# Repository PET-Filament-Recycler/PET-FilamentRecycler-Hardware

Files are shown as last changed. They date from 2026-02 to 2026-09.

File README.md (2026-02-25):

# PET Filament Recycler

A DIY project to recycle PET bottles into 3D printing filament, integrated with an Android app for Bluetooth-based control and monitoring.

---

## Overview

This project builds a machine that cuts PET plastic bottles into strips, then heats and extrudes them into usable 1.75 mm 3D printer filament. An Arduino-based controller manages the heating element and stepper motor via PID control, while an Android app communicates with the machine over Bluetooth to set parameters, start/stop operation, and view command logs.

---

## Features

- **PID temperature control** for the heating block (target: ~200 °C)
- **Stepper motor control** for filament extrusion speed
- **Bluetooth connectivity** (HC-05 / Serial1) for wireless control
- **Android app** with:
  - Bluetooth device discovery and connection
  - Real-time temperature and speed display
  - Start / Stop / Save settings commands
  - Bluetooth command log viewer (SQLite)
- **EEPROM persistence** – temperature and speed settings survive power cycles
- **Custom PCB** design included (GERBER files provided)
- **3D-printable parts** for the mechanical assembly (15 STL files)

---

## Repository Structure

```
PET-Filament-Recycler/
├── 0.1/
│   ├── arduino/
│   │   ├── Firmware_1/          # Original Arduino Nano firmware
│   │   ├── Firmware_1.1/        # Updated Arduino UNO R4 firmware (Bluetooth, EEPROM)
│   │   └── tests/               # Individual component test sketches
│   │       ├── Bluetooth_Test/
│   │       ├── Button_Test/
│   │       ├── LCD_Test/
│   │       ├── PID_Test/
│   │       ├── PWM_Test/
│   │       ├── Stepper_Test/
│   │       └── Thermistor_Test/
│   └── docs/
│       ├── 3D Files STL/        # 3D-printable part files
│       ├── AppLayout/           # UI design mockups (PNG)
│       ├── PCB GERBERs/         # PCB manufacturing files
│       ├── TestResult/          # Component test result photos/videos
│       ├── FlowChart.png        # App ↔ Arduino interaction flow chart
│       └── partList.md          # Bill of materials
└── Android App/                 # Android Studio project (Java)
    └── app/src/main/java/com/petfilament/recycler/
        ├── MainActivity.java
        ├── ControlActivity.java
        ├── BluetoothManager.java
        ├── LogActivity.java
        ├── LogsAdapter.java
        └── DatabaseHelper.java
```

---

## Bill of Materials

| Qty | Component |
|-----|---|
| 1 | Arduino NANO (Firmware 1) / Arduino UNO R4 (Firmware 1.1) |
| 6 | 608ZZ Bearing |
| 1 | NEMA 17 Stepper Motor |
| 1 | I²C LCD Screen (16×2) |
| 1 | TMC2208 Stepper Driver |
| 1 | 3D Printer Aluminum Heating Block |
| 2 | IRF3205 MOSFETs |
| 1 | HC-05 Bluetooth Module |
| 1 | 10 kΩ Potentiometer |
| 1 | Push Button |
| 2 | 3 mm Red LEDs |
| 3 | 10 kΩ Resistors |
| 2 | 10 Ω Resistors |
| 2 | 1.8 kΩ Resistors |
| 1 | 10 µF Capacitor |
| 2 | 100 µF Capacitors |
| — | Female pin headers, screw terminals, M3 screws |

> Full details: [`0.1/docs/partList.md`](0.1/docs/partList.md)

---

## 3D Printed Parts

All STL files are located in [`0.1/docs/3D Files STL/`](0.1/docs/3D%20Files%20STL/).

| File | Description |
|---|---|
| `Board_leg.stl` | PCB mounting leg |
| `Cutter_support.stl` / `Cutter_support_V2.stl` | Bottle-strip cutter support |
| `Filament_aligner.stl` | Guides filament into the heater |
| `Gear_spool_A.stl` / `Gear_spool_B.stl` | Drive gear pair |
| `PET_Spool_A.stl` / `PET_Spool_B.stl` | PET bottle spool halves |
| `PET_Spool_support_A.stl` / `PET_Spool_support_B.stl` | Spool support brackets |
| `Pully.stl` | Motor pulley |
| `Small_gear.stl` | Secondary drive gear |
| `Spool_holder_side_A.stl` / `Spool_holder_side_B.stl` | Spool holder sides |
| `Stepper_support.stl` | NEMA 17 motor mount |

---

## PCB

Gerber files for the custom PCB are in [`0.1/docs/PCB GERBERs/`](0.1/docs/PCB%20GERBERs/). Reference photos of the assembled board are also in [`0.1/docs/`](0.1/docs/).

The circuit is based on the [Electronoobs PET bottle recycler](http://electronoobs.com/eng_arduino_tut174.php) design, with additions for the Bluetooth module.

---

## Arduino Firmware

### Firmware 1 (`0.1/arduino/Firmware_1/`)
- Target board: **Arduino Nano**
- Controls heating element (PID), stepper motor speed (potentiometer), and LCD display.
- Required libraries: `LiquidCrystal_I2C`, `thermistor` ([Electronoobs](https://electronoobs.com/eng_arduino_tut_thermistor.php)), `AccelStepper`

### Firmware 1.1 (`0.1/arduino/Firmware_1.1/`)
- Target board: **Arduino UNO R4 WiFi/Minima**
- Adds Bluetooth serial (`Serial1`) communication and EEPROM settings persistence.
- Replaces the thermistor library with a manual NTC 100 k / β=3950 calculation.
- Required libraries: `hd44780`, `AccelStepper`

#### Supported Bluetooth Commands

| Command | Description |
|---|---|
| `SET_TEMP:<value>` | Set target temperature (0–300 °C) |
| `SET_SPEED:<value>` | Set motor speed (0–1000 steps/s) |
| `START` | Enable stepper motor |
| `STOP` | Disable stepper motor |
| `GET_STATUS` | Returns `TEMP:x,SPEED:x,STATUS:ON/OFF,CONNECTED:yes` |
| `SAVE` | Persist current temperature and speed to EEPROM |

---

## Android App

Located in [`Android App/`](Android%20App/). Open with **Android Studio**.

### Screens

| Activity | Description |
|---|---|
| `MainActivity` | Home screen; navigate to Control screen |
| `ControlActivity` | Bluetooth discovery, connection, machine control, live status |
| `LogActivity` | View history of all sent/received Bluetooth commands |

### Permissions Required

- `BLUETOOTH_SCAN` / `BLUETOOTH_CONNECT` (Android 12+)
- `ACCESS_FINE_LOCATION` (required for Bluetooth scanning on all versions)

### Build

1. Open the `Android App/` folder in Android Studio.
2. Sync Gradle and build the project.
3. Install on a device running Android 8.0 (API 26) or later.

---

## Setup & Usage

1. **Print** all 3D parts and assemble the mechanical frame.
2. **Solder** the PCB using the GERBER files and the parts list above.
3. **Flash** the Arduino firmware using the Arduino IDE.
4. **Pair** your Android phone with the HC-05 Bluetooth module (default PIN: `1234`).
5. **Install** the Android app on your phone.
6. Open the app, tap **Navigate → Control**, then select the HC-05 device and tap **Connect**.
7. Set the desired temperature and speed, tap **Save**, then tap **Start** to begin extruding.
8. Monitor live temperature and speed on the Control screen, or tap **View Logs** to review command history.

---

## References

- Electronoobs PET Recycler Tutorial: <http://electronoobs.com/eng_arduino_tut174.php>
- HC-05 Bluetooth Module Guide: <https://www.electronicshub.org/arduino-hc-05-bluetooth-module-tutorial/>

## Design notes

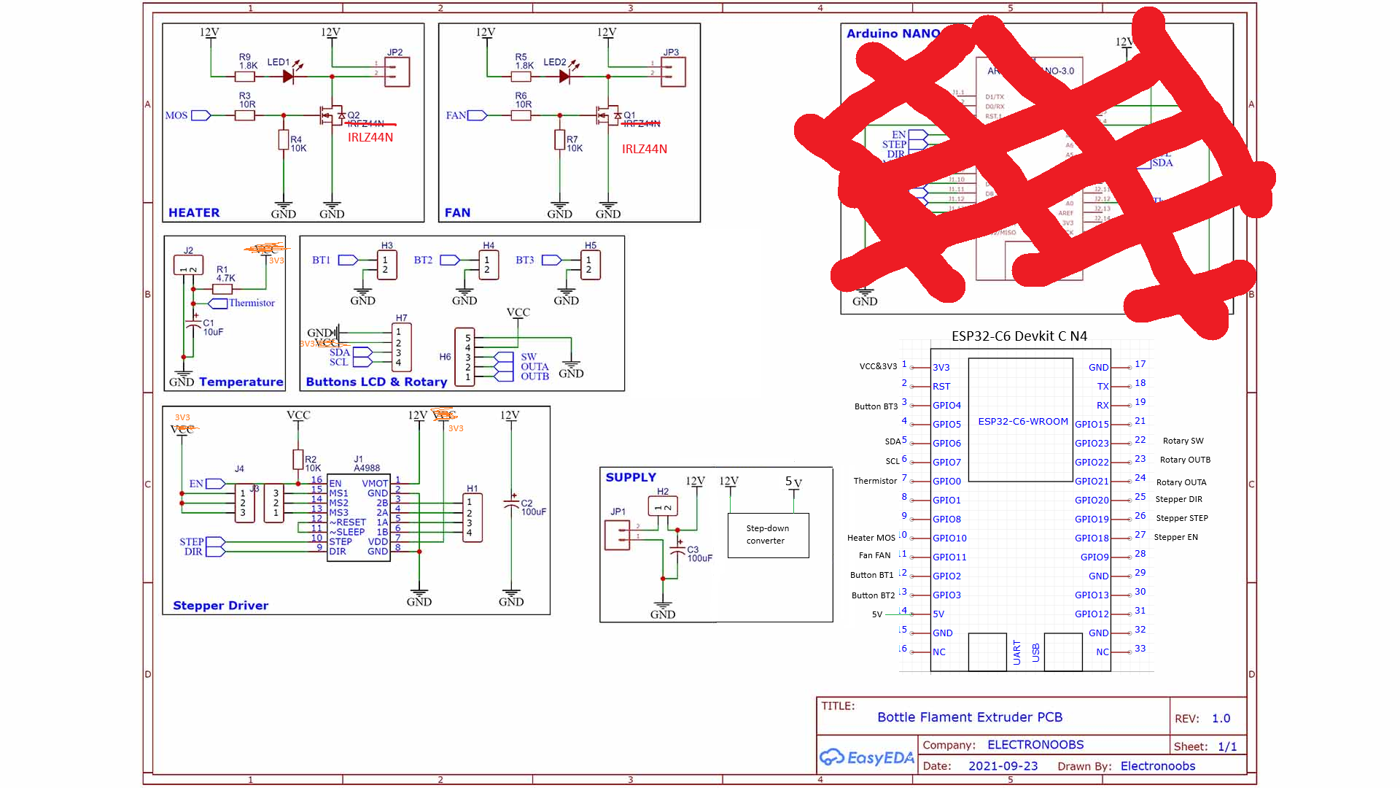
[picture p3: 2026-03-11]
0.2/docs/bottle Flament Extruder PCB ESP32 v1.png

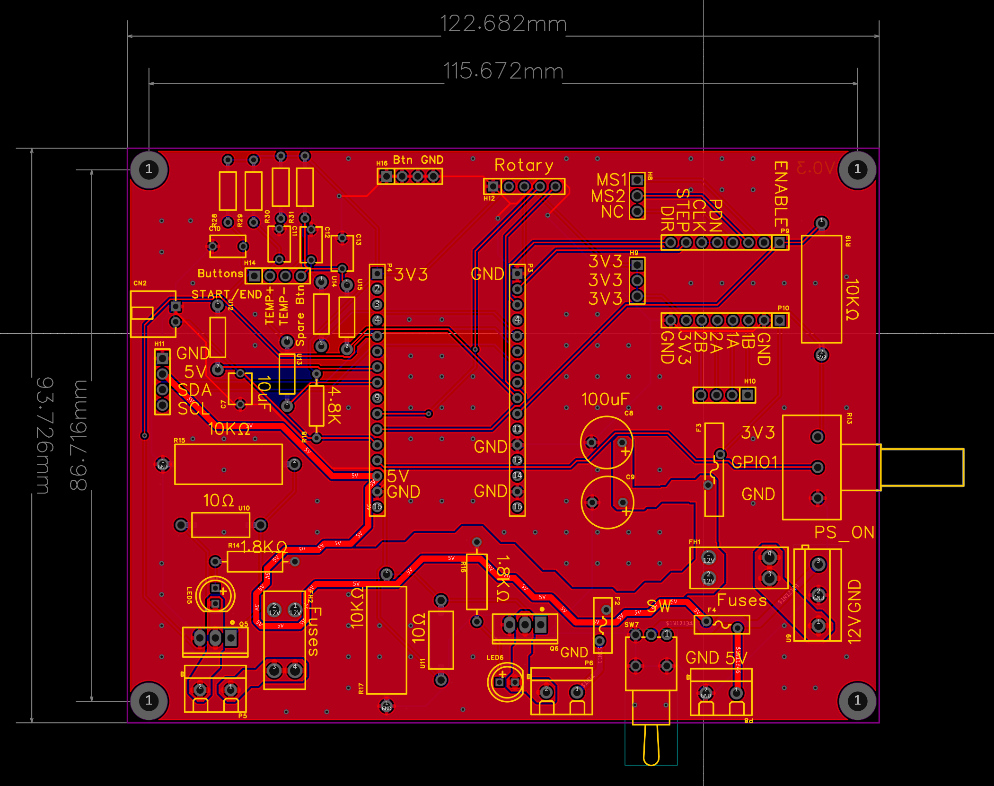
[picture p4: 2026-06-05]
0.2/docs/bottle Flament Extruder PCB ESP32 v3.png

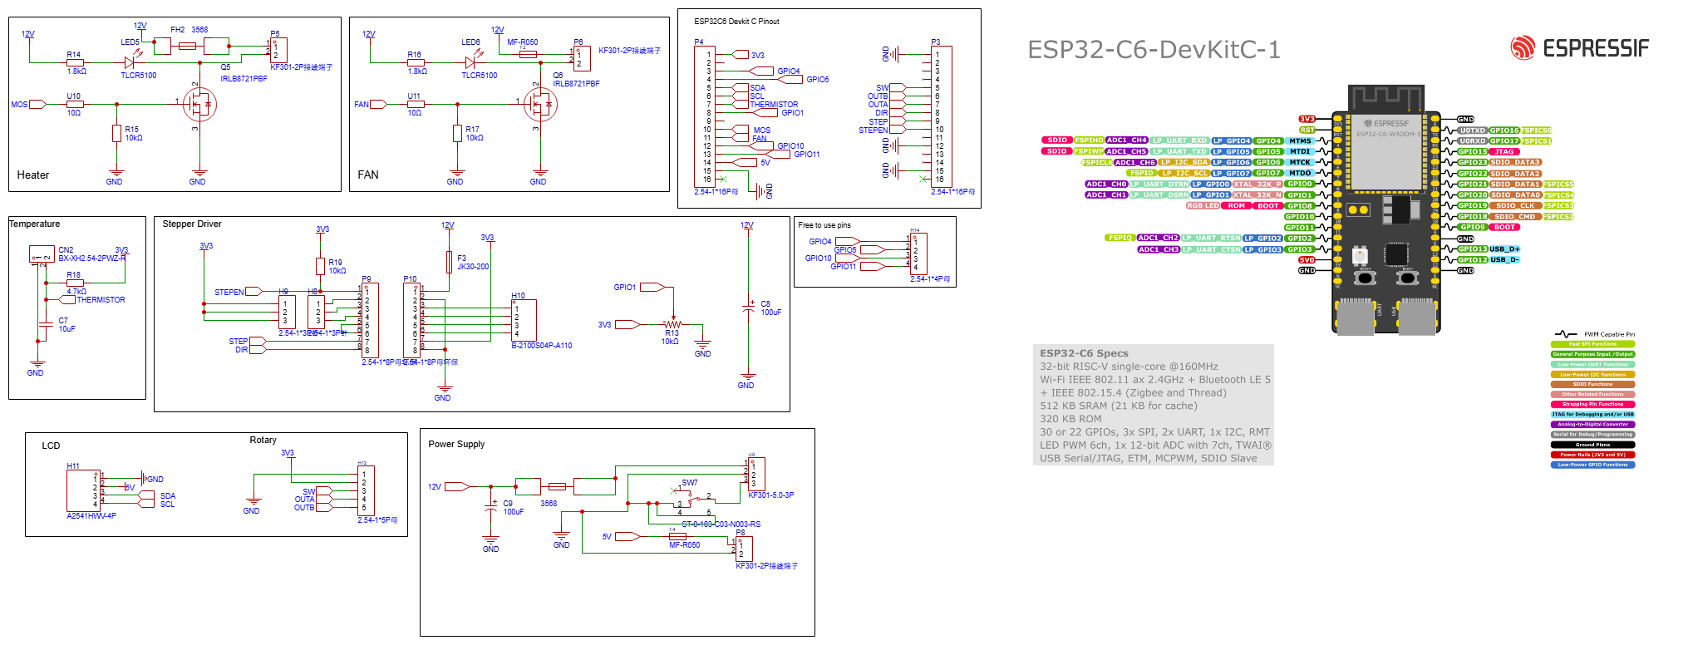
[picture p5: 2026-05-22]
0.2/docs/bottle Flament Extruder SCH ESP32 v2.png

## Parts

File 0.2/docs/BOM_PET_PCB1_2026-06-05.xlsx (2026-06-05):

No. | Quantity | Comment | Designator | Footprint | Value | Manufacturer Part | Manufacturer | Supplier Part | Supplier | Primary Category | Secondary Category | Pin Count | LCSC Stock | LCSC Price | JLCPCB Stock | JLCPCB Price | Layer | Mounting Style | Add into BOM | Convert to PCB | 3D Model Title | Device | Name | Unique ID | Fuse Type
1 | 1 | 10uF | C7 | CAP-TH_L5.1-W3.8-P5.08-D0.5 | 10uF | C322C106K3R5TA | KEMET(基美) | C1623600 | LCSC | Capacitors | Multilayer Ceramic Capacitors MLCC - Leaded | 2 |  |  | 0 | 0.0455 | T | DIP | yes |  | CAP-TH_L5.1-W3.8-P5.08-D0.5 | C322C106K3R5TA | 10uF | gge53
2 | 2 | 100uF | C8,C9 | CAP-TH_BD8.2-P5.00-D0.6-FD_MAL211650101E3 | 100uF | MAL211650101E3 | VISHAY(威世) | C1600087 | LCSC | Capacitors | Aluminum Electrolytic Capacitors - Leaded | 2 |  |  | 341 | 0.1743 | T | DIP | yes |  | CAP-TH_BD8.2-P5.00-D0.6-FD_MAL211650101E3 | MAL211650101E3 | 100uF | gge56,gge57
3 | 4 | 100nF | C10,C11,C12,C13 | CAP-TH_L5.8-W3.6-P5.0-D0.6 | 100nF | 178MU0002 | KNSCHA(科尼盛) | C5632426 | LCSC | Capacitors | Multilayer Ceramic Capacitors MLCC - Leaded | 2 |  |  | 144738 | 0.0021 | T | DIP | yes |  | CAP-TH_L5.8-W3.6-P5.0-D0.6 | 178MU0002 | 100nF | gge64,gge65,gge66,gge67
4 | 1 | BX-XH2.54-2PWZ-R | CN2 | CONN-TH_2P-P2.50_BX-XH2.54-2PWZ |  | BX-XH2.54-2PWZ-R | Bossie(博锡) | C22388493 | LCSC | Connectors | Wire To Board Connector | 2 |  |  | 9214 | 0.0028 | T | DIP | yes |  | CONN-TH_2P-P2.50_BX-XH2.54-2PWZ | BX-XH2.54-2PWZ-R | BX-XH2.54-2PWZ-R | gge15
5 | 2 | MF-R050 | F2,F4 | FUSE-TH_L9.0-W3.0-P5.10-D0.6-S1.10 |  | MF-R050 | BOURNS | C208476 | LCSC | Circuit Protection | Resettable Fuses | 2 |  |  | 840 | 0.0203 | T | DIP | yes |  | FUSE-TH_L8.9-W3.0-H13.5-P5.1-D0.5-S1.1 | MF-R050 | MF-R050 | gge50,gge58
6 | 1 | JK30-200 | F3 | FUSE-TH_L15.2-W3.0-P5.10-D0.50-S2.00 |  | JK30-200 | JK(金科) | C369104 | LCSC | Circuit Protection | Resettable Fuses | 2 |  |  | 23203 | 0.0088 | T | DIP | yes |  | FUSE-TH_L15.2-W3.0-H15.2-P5.10-D0.8-S2.00 | JK30-200_C369104 | JK30-200 | gge55
7 | 2 | 3568 | FH1,FH2 | FUSE-SMD_4P-L16.0-W6.7-P3.40 |  | 3568 | Keystone | C5249699 | LCSC | Circuit Protection | Fuseholders | 4 |  |  | 3478 | 0.2129 | T | DIP | yes |  | FUSE-TH_4P-L16.0-W6.7-P3.40 | 3568 | 3568 | gge30,gge31 | Blade
8 | 2 | 2.54-1*3P针 | H8,H9 | HDR-TH_3P-P2.54-V-M-1 |  | 2.54-1*3P针 | BOOMELE(博穆精密) | C49257 | LCSC | Connectors | Pin Headers | 3 |  |  | 468060 | 0.0036 | T | DIP | yes |  | HDR-M-2.54_1x3 | 2.54-1*3P针 | 2.54-1*3P针 | gge20,gge21
9 | 1 | B-2100S04P-A110 | H10 | HDR-TH_4P-P2.54-V-M |  | B-2100S04P-A110 | Ckmtw(灿科盟) | C124378 | LCSC | Connectors | Pin Headers | 4 |  |  | 79752 | 0.0082 | T | DIP | yes |  | HDR-TH_4P-P2.54-M-LI-1X4P | B-2100S04P-A110 | B-2100S04P-A110 | gge22
10 | 1 | A2541HWV-4P | H11 | HDR-TH_4P-P2.54-V_A2541HWV-4P |  | A2541HWV-4P | CJT(长江连接器) | C225501 | LCSC | Connectors | Female Headers | 4 |  |  | 0 | 0.0152 | T | DIP | yes |  | HDR-F-2.54_1x4 | A2541HWV-4P | A2541HWV-4P | gge25
11 | 1 | 2.54-1*5P母 | H12 | HDR-TH_5P-P2.54-V-F |  | 2.54-1*5P母 | BOOMELE(博穆精密) | C50950 | LCSC | Connectors | Female Headers | 5 |  |  | 156236 | 0.0119 | T | DIP | yes |  | HDR-TH_5P-P2.54-V-F | 2.54-1*5P母 | 2.54-1*5P母 | gge26
12 | 2 | 2.54-1*4P母 | H14,H16 | HDR-TH_4P-P2.54-V-F |  | 2.54-1*4P母 | BOOMELE(博穆精密) | C2718488 | LCSC | Connectors | Female Headers | 4 |  |  | 185971 | 0.0115 | T | DIP | yes |  | HDR-TH_4P-P2.54-V-F | 2.54-1*4P母 | 2.54-1*4P母 | gge36,gge36_2
13 | 2 | TLCR5100 | LED5,LED6 | ED-TH_BD5.8-P2.54-R-FD |  | TLCR5100 | VISHAY(威世) | C7069388 | LCSC | Optoelectronics | LED Indication - Discrete | 2 |  |  | 7277 | 0.0671 | T | DIP | yes |  | ED-TH_BD5.8-P2.54-R-FD | TLCR5100 | TLCR5100 | gge45,gge45_1
14 | 2 | 2.54-1*16P母 | P3,P4 | HDR-TH_16P-P2.54-V-F-1 |  | 2.54-1*16P母 | BOOMELE(博穆精密) | C66987 | LCSC | Connectors | Female Headers | 16 |  |  | 2944 | 0.0157 | T | DIP | yes |  | HDR2.54-F-LI-1X16P | 2.54-1*16P母 | 2.54-1*16P母 | gge1,gge2
15 | 3 | KF301-2P接线端子 | P5,P6,P8 | CONN-TH_XY301V-A-5.0-2P |  | KF301-2P接线端子 |  | C9900016950 | LCSC |  |  | 2 |  |  | 0 | 0.0059 | T | DIP | yes |  | CONN-TH_XY301V-A-5.0-2P | KF301-2P接线端子 | KF301-2P接线端子 | gge7,gge10,gge38
16 | 2 | 2.54-1*8P母环保 | P9,P10 | HDR-TH_8P-P2.54-V-F |  | 2.54-1*8P母环保 | BOOMELE(博穆精密) | C27438 | LCSC | Connectors | Female Headers | 8 |  |  | 163707 | 0.0158 | T | DIP | yes |  | HDR-TH_8P-P2.54-V-F | 2.54-1*8P母环保 | 2.54-1*8P母环保 | gge40,gge41
17 | 2 | IRLB8721PBF | Q5,Q6 | TO-220-3_L10.0-W4.5-P2.54-L |  | IRLB8721PBF | Infineon(英飞凌) | C153222 | LCSC | Transistors/Thyristors | MOSFETs | 3 |  |  | 0 | 0.4344 | T | DIP | yes |  | TO-220-3_L10.0-W4.5-P2.54-L | IRLB8721PBF | IRLB8721PBF | gge48,gge49
18 | 1 | 10kΩ | R13 | RES-ADJ-TH_P160KN2-0QC20B100K | 10kΩ | P160KN2-4QC20B10K | TT Electronics | C7018262 | LCSC | Resistors | Potentiometers, Variable Resistors | 3 |  |  | 6 | 0.2895 | T | DIP | yes |  | RES-ADJ-TH_P160KN2-0QC20B100K | P160KN2-4QC20B10K | 10kΩ | gge35
19 | 2 | 1.8kΩ | R14,R16 | RES-TH_BD3.3-L9.0-P13.00-D0.6 | 1.8kΩ | MF1/2W-1.8KΩ±1% T | CCO(千志电子) | C119421 | LCSC | Resistors | Through Hole Resistors | 2 |  |  | 4474 | 0.0036 | T | DIP | yes |  | RES-TH_BD3.3-L9.0-P13.00-D0.6 | MF1/2W-1.8KΩ±1% T | 1.8kΩ | gge44,gge44_1
20 | 3 | 10kΩ | R15,R17,R19 | RES-TH_BD6.5-L17.5-P21.50-D0.8 | 10kΩ | ROX3SJ10K | TE Connectivity(泰科电子) | C1365951 | LCSC | Resistors | Through Hole Resistors | 2 |  |  | 1049 | 0.0307 | T | DIP | yes |  | RES-TH_BD6.5-L17.5-P21.50-D0.8 | ROX3SJ10K | 10kΩ | gge47,gge51,gge54
21 | 1 | 4.7kΩ | R18 | RES-TH_BD2.3-L6.5-P10.50-D0.5 | 4.7kΩ | MF1/4W-4.7KΩ±1% T | CCO(千志电子) | C119339 | LCSC | Resistors | Through Hole Resistors | 2 |  |  | 167017 | 0.0018 | T | DIP | yes |  | RES-TH_D2.3-L6.5-P10.50 | MF1/4W-4.7KΩ±1% T | 4.7kΩ | gge52
22 | 4 | 10kΩ | R28,R29,R30,R31 | RES-TH_BD2.7-L6.2-P10.20-D0.4 | 10kΩ | MF1/4W-10K±1%-ST52 | VO(翔胜) | C2903232 | LCSC | Resistors | Through Hole Resistors | 2 |  |  | 210803 | 0.0011 | T | DIP | yes |  | RES-TH_BD2.7-L6.2-P10.20-D0.4 | MF1/4W-10K±1%-ST52 | 10kΩ | gge68,gge69,gge70,gge71
23 | 4 | Screw-Hole-M3 | SCREW1,SCREW2,SCREW3,SCREW4 | Screw-Hole-M3 |  |  |  |  |  |  |  | 1 |  | 4.9564 |  |  | T | DIP | yes |  |  | Screw-Hole-M3 |  | $1,$2,$3,$4
24 | 1 | ST-0-103-C03-N003-RS | SW7 | SW-TH_ST-0-103-C03-N003-RS |  | ST-0-103-C03-N003-RS | YUEN FUNG(源丰) | C1788490 | LCSC | Switches | Toggle Switches | 5 |  |  | 1091 | 0.1191 | T | DIP | yes |  | SW-TH_ST-0-103-C03-N003-RS | ST-0-103-C03-N003-RS | ST-0-103-C03-N003-RS | gge59
25 | 1 | KF301-5.0-3P | U9 | CONN-TH_3P-P5.00_KF301-5.0-3P |  | KF301-5.0-3P | KEFA(科发) | C474882 | LCSC | Connectors | Screw Terminal Blocks | 3 |  |  | 12801 | 0.0204 | T | DIP | yes |  | CONN-TH_3P-P5.00_KF301-5.0-3P | KF301-5.0-3P | KF301-5.0-3P | gge42
26 | 2 | 10Ω | U10,U11 | RES-TH_BD3.5-L9.0-P13.00-D0.8 | 10Ω | 保险电阻10Ω/1W±5%,H-FKN | 双羽 | C111941 | LCSC | Resistors | Through Hole Resistors | 2 |  |  | 0 | 0.0052 | T | DIP | yes |  | RES-TH_BD3.5-L9.0-P13.00-D0.8 | 保险电阻10Ω/1W±5%,H-FKN | 10Ω | gge46,gge46_1
27 | 4 | 100Ω | U12,U13,U14,U15 | RES-TH_BD2.5-L6.5-P10.50-D0.6 | 100Ω | MBB02070C1000FCT00 | VISHAY(威世) | C1366145 | LCSC | Resistors | Through Hole Resistors | 2 |  |  | 10895 | 0.0062 | T | DIP | yes |  | RES-TH_D2.3-L6.5-P10.50 | MBB02070C1000FCT00 | 100Ω | gge72,gge73,gge74,gge75

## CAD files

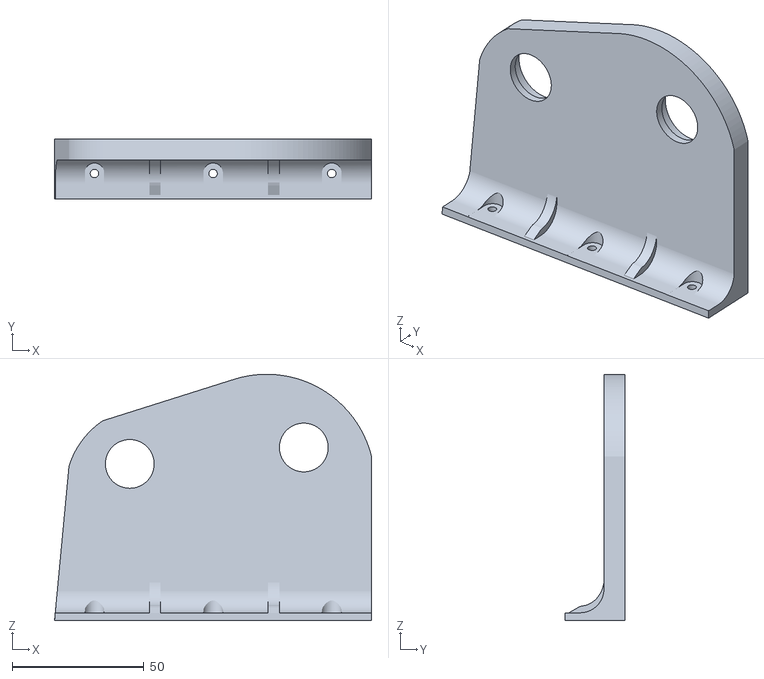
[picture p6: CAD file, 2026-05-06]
0.2/docs/3D model/Spool_holder_side_B(without_logo).stl
120.2 x 22.7 x 93.5

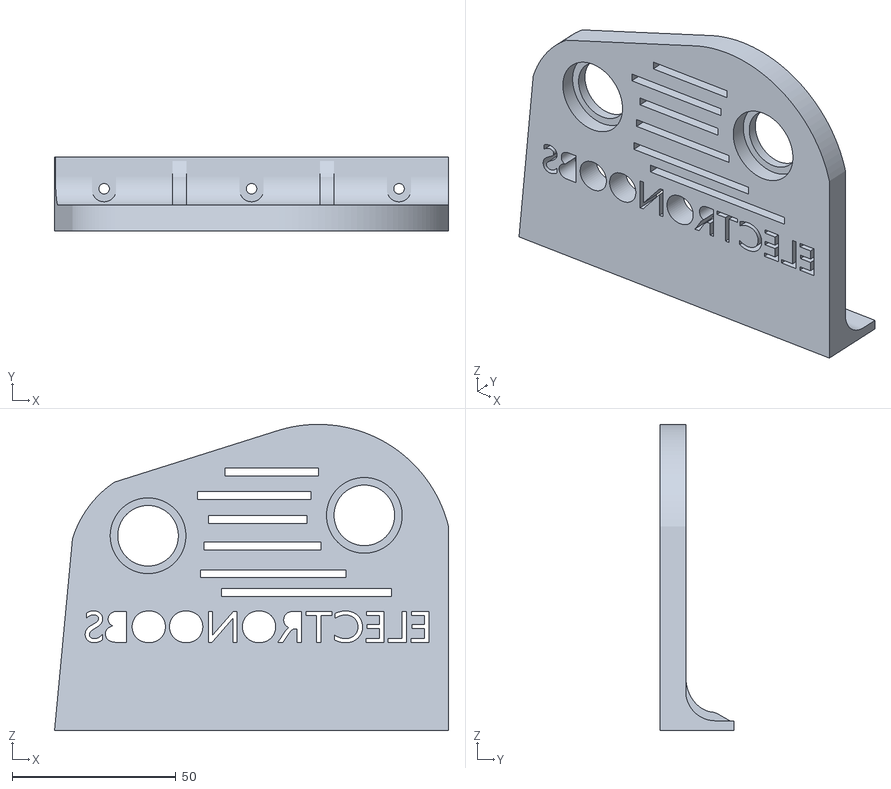
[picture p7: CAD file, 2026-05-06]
0.2/docs/3D model/Spool_holder_side_A.stl
120.2 x 22.6 x 93.5

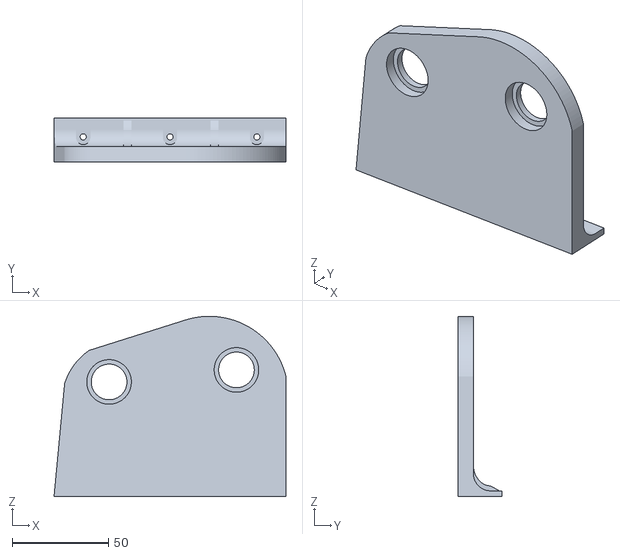
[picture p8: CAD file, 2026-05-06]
0.2/docs/3D model/Spool_holder_side_A(without_logo).stl
120.2 x 22.6 x 93.5

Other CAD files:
0.2/docs/3D model/Spool_holder_side_B (repaired).stl
0.2/docs/3D model/Spool_holder_side_A(without_logo).blend
0.2/docs/3D model/Spool_holder_side_B(without_logo).blend

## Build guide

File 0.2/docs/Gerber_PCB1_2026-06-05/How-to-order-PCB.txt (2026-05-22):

How to Order PCB

Please refer to:
https://prodocs.easyeda.com/en/pcb/order-order-pcb/index.html

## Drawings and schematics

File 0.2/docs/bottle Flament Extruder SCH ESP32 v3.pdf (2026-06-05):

Heater | FAN

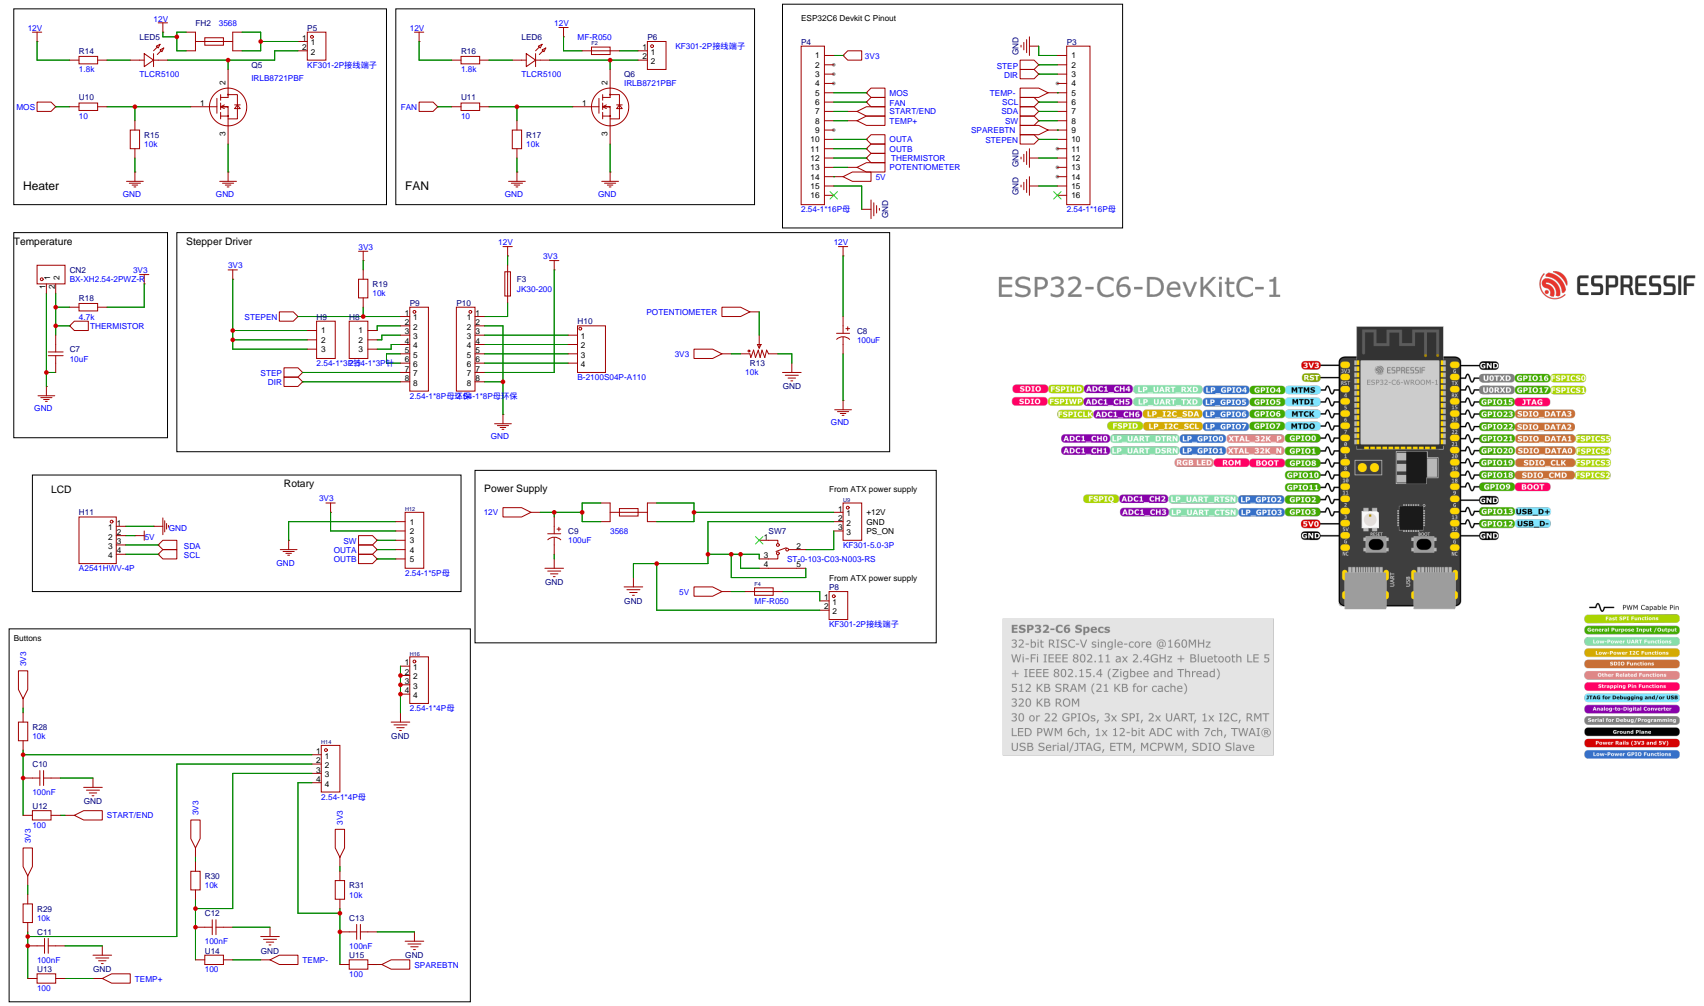
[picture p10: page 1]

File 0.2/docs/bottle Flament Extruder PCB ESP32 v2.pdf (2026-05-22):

## Temperature

Spare GPIO | Rotary | Stepper Driver

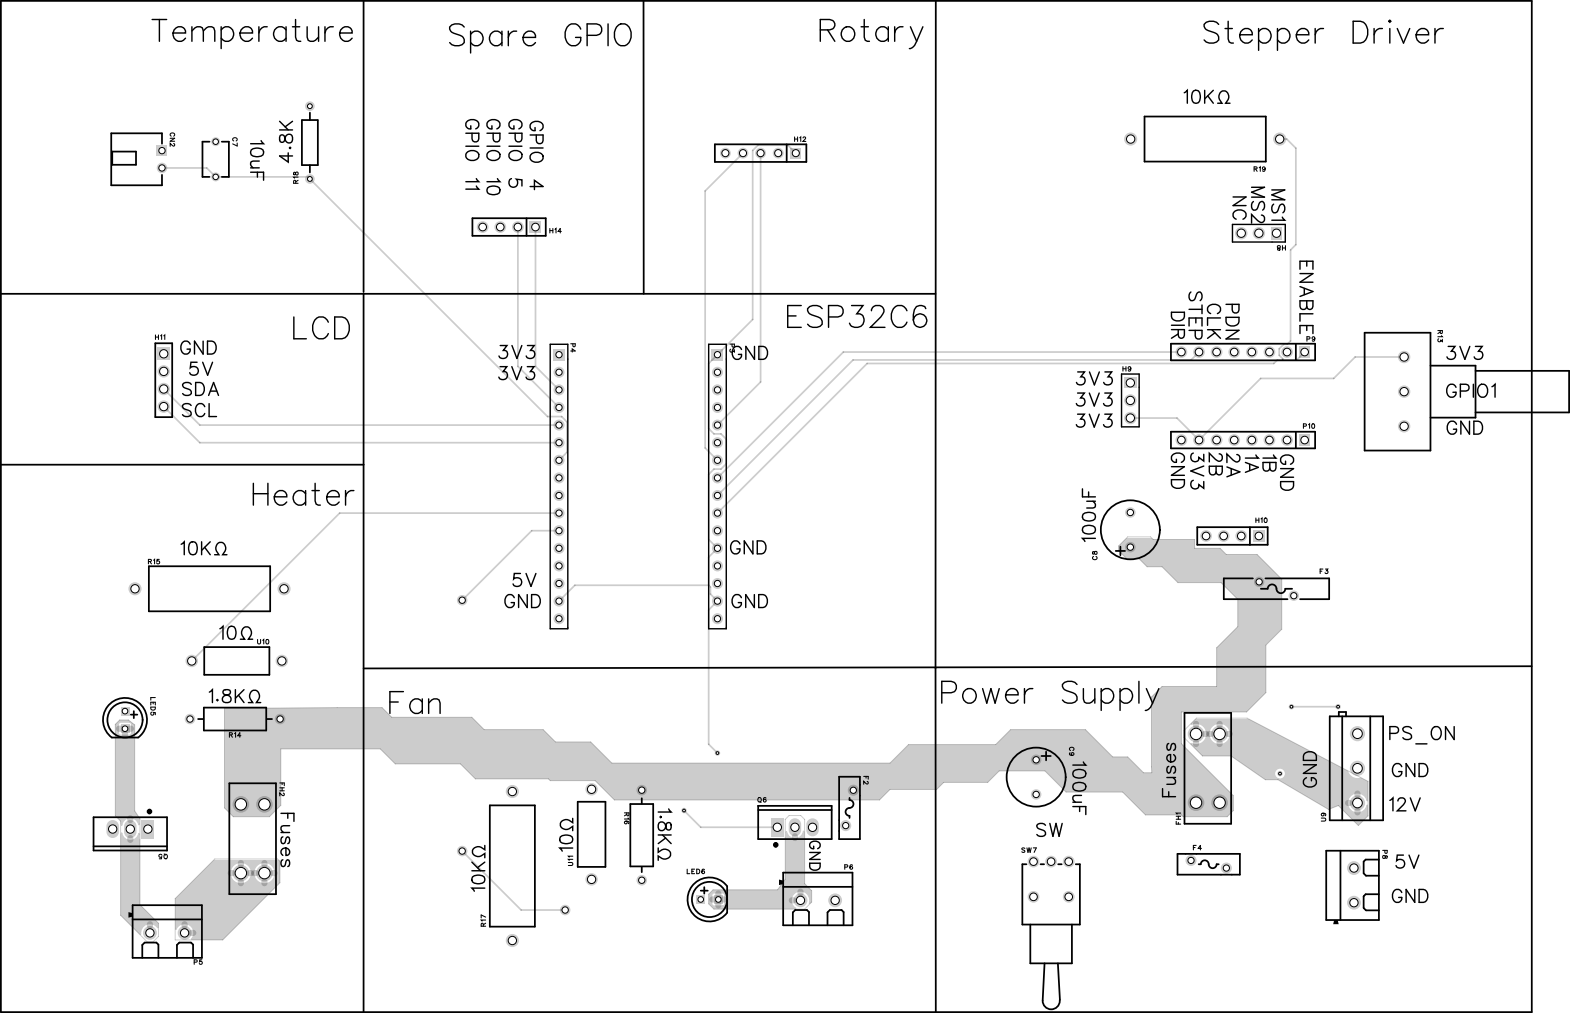
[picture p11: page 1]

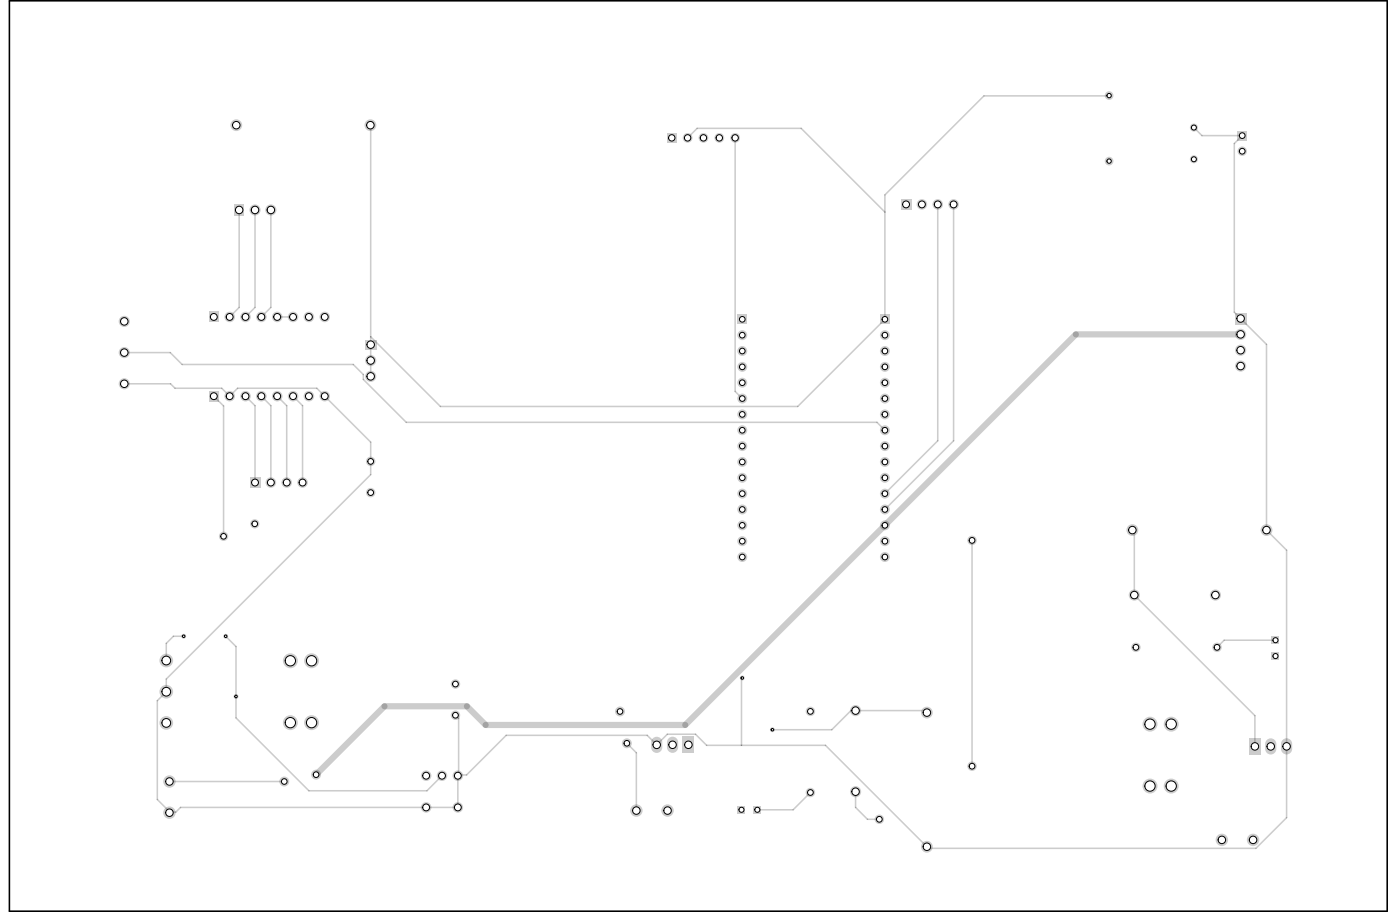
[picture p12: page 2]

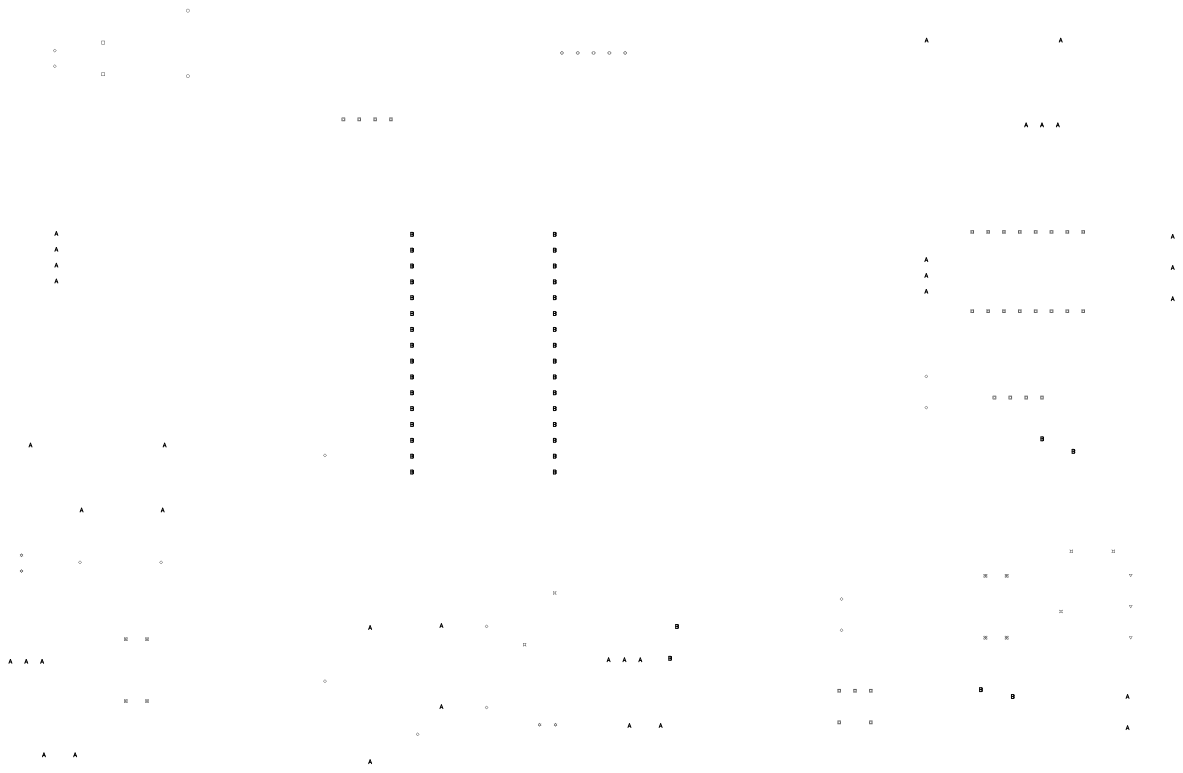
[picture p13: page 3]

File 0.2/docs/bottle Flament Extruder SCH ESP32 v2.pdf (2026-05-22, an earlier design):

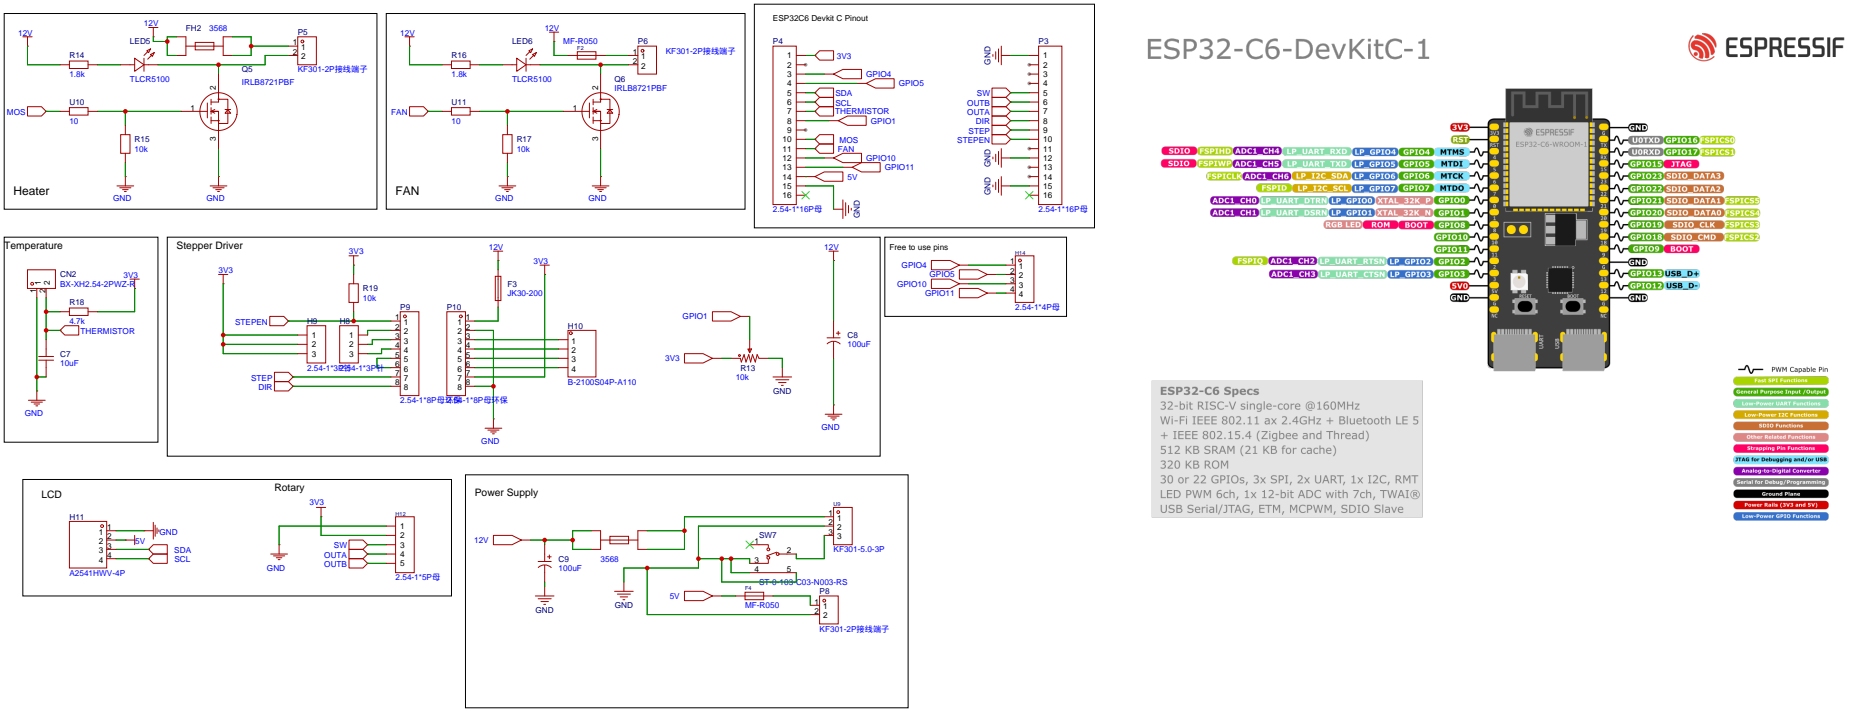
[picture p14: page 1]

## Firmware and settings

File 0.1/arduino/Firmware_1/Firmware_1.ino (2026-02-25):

//LCD config
#include <Wire.h> 
#include <LiquidCrystal_I2C.h>
LiquidCrystal_I2C lcd(0x3f,16,2);  //sometimes the adress is not 0x3f. Change to 0x27 if it dosn't work.

//Thermistor needed libraries
#include <thermistor.h>           //Download it here: https://electronoobs.com/eng_arduino_thermistor.php
thermistor therm1(A0,0);          //Connect thermistor on A0, 0 represents TEMP_SENSOR_0 ( configuration.h for more)


//I/O
int PWM_pin = 5;                  //Pin for PWM signal to the MOSFET driver (the BJT npn with pullup)
int speed_pot = A1;
int but1 = 7;
int EN = 2;
int STEP = 3;
int DIR = 4;
int LED = 13;

//Variables
float set_temperature = 200;            //Default temperature setpoint. Leave it 0 and control it with rotary encoder
float temperature_read = 0.0;
float PID_error = 0;
float previous_error = 0;
float elapsedTime, Time, timePrev;
float PID_value = 0;
int button_pressed = 0;
int menu_activated=0;
float last_set_temperature = 0;
int max_PWM = 255;

//Stepper Variables
int max_speed = 1000;
int main_speed = 0;
bool but1_state = true;
bool activate_stepper = false;
int rotating_speed = 0;



#include <AccelStepper.h>
// Define a stepper and the pins it will use
AccelStepper stepper1(1, STEP, DIR); // (Type of driver: with 2 pins, STEP, DIR)

//PID constants
//////////////////////////////////////////////////////////
int kp = 90;   int ki = 30;   int kd = 80;
//////////////////////////////////////////////////////////

int PID_p = 0;    int PID_i = 0;    int PID_d = 0;
float last_kp = 0;
float last_ki = 0;
float last_kd = 0;

int PID_values_fixed =0;



void setup() {  
  pinMode(EN, OUTPUT);
  digitalWrite(EN, HIGH);     //Stepper driver is disabled
  stepper1.setMaxSpeed(max_speed);  
  pinMode(but1, INPUT_PULLUP);
  pinMode(speed_pot, INPUT);
  pinMode(LED, OUTPUT);
  digitalWrite(LED, LOW);
  
  pinMode(PWM_pin,OUTPUT);
  TCCR0B = TCCR0B & B11111000 | B00000010;    // D5 and D6 PWM frequency of 7812.50 Hz
  Time = millis();

  TCCR1A = 0;             //Reset entire TCCR1A register
  TCCR1B = 0;             //Reset entire TCCR1B register
  TCCR1B |= B00000010;    //Prescaler /8
  TCCR1B |= (1 << WGM12); //CTC mode (Clear Timer on Compare Match)
  OCR1A = 2000;           //Compare value for ~100 Hz step rate (16MHz/8/2000 = 1000 Hz)
  TCNT1 = 0;              //Reset Timer 1 value to 0
  TIMSK1 |= (1 << OCIE1A); //Enable Timer1 compare match A interrupt
  
  lcd.init();
  lcd.backlight();
}

void loop() {
  if(!digitalRead(but1) && but1_state){
    but1_state = false;
    activate_stepper = !activate_stepper;
    delay(10);
  }
  else if(digitalRead(but1) && !but1_state){
    but1_state = true;
  }
  
  if(activate_stepper){
    digitalWrite(LED, HIGH);
    digitalWrite(EN, LOW);    //We activate stepper driver
    rotating_speed = map(analogRead(speed_pot),0,1024,main_speed,max_speed);
    stepper1.setSpeed(rotating_speed);
    //stepper1.runSpeed();
  }
  else
  {
    digitalWrite(EN, HIGH);    //We deactivate stepper driver
    digitalWrite(LED, LOW);
    stepper1.setSpeed(0);
    stepper1.runSpeed();
  }
  
  // First we read the real value of temperature
  temperature_read = therm1.analog2temp(); // read temperature
  
  //Next we calculate the error between the setpoint and the real value
  PID_error = set_temperature - temperature_read + 6;
  //Calculate the P value
  PID_p = 0.01*kp * PID_error;
  //Calculate the I value in a range on +-6
  PID_i = 0.01*PID_i + (ki * PID_error);
  
  
  //For derivative we need real time to calculate speed change rate
  timePrev = Time;                            // the previous time is stored before the actual time read
  Time = millis();                            // actual time read
  elapsedTime = (Time - timePrev) / 1000; 
  //Now we can calculate the D calue
  PID_d = 0.01*kd*((PID_error - previous_error)/elapsedTime);
  //Final total PID value is the sum of P + I + D
  PID_value = PID_p + PID_i + PID_d;

  
  //We define PWM range between 0 and 255
  if(PID_value < 0){
    PID_value = 0;
  }
  if(PID_value > max_PWM){
    PID_value = max_PWM;
  }
  
  //Now we can write the PWM signal to the mosfet on digital pin D5
  analogWrite(PWM_pin,PID_value);
  previous_error = PID_error;     //Remember to store the previous error for next loop.
  
  delay(250); //Refresh rate + delay of LCD print
  lcd.clear();
  
  lcd.setCursor(0,0);
  lcd.print("T: ");  
  lcd.print(temperature_read,1);
  lcd.print(" S: ");  
  lcd.print(rotating_speed);
  
  lcd.setCursor(0,1);
  lcd.print("PID: ");
  lcd.print(PID_value);
 
}//Void loop end


ISR(TIMER1_COMPA_vect){
  TCNT1  = 0;                  //First, set the timer back to 0 so it resets for next interrupt
  stepper1.runSpeed();
}

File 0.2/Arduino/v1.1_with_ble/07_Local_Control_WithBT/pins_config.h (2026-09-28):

#ifndef PET_BENCH_NO_STEPPER_ON_UART
#define PET_BENCH_NO_STEPPER_ON_UART 0
#endif

constexpr uint8_t BTN_START_END = 0;
constexpr uint8_t BTN_TEMP_PLUS = 1;
constexpr uint8_t BTN_TEMP_MINUS = 23;
constexpr uint8_t POT_PIN = 3;

constexpr uint8_t HEATER_PIN = 6;
constexpr uint8_t FAN_PIN = 7;
constexpr uint8_t THERMISTOR_PIN = 2;
#if PET_BENCH_NO_STEPPER_ON_UART
constexpr uint8_t STEP_PIN = 4;
constexpr uint8_t DIR_PIN = 5;
#else
constexpr uint8_t STEP_PIN = 16;
constexpr uint8_t DIR_PIN = 17;
#endif
constexpr uint8_t EN_PIN = 18;
constexpr uint8_t I2C_SDA_PIN = 21;
constexpr uint8_t I2C_SCL_PIN = 22;

constexpr uint8_t DRIVER_ENABLE_LEVEL = LOW;
constexpr uint8_t DRIVER_DISABLE_LEVEL = HIGH;

constexpr double BETA = 3950.0;
constexpr double R0 = 10000.0;
constexpr double SERIES_R = 4700.0;
// Named THERMISTOR_T0_K to avoid clash with ESP32 core pin alias T0.
constexpr double THERMISTOR_T0_K = 298.15;
constexpr int ADC_MAX = 4095;

constexpr float STEPPER_SPEED_MIN = 0.0;
constexpr float STEPPER_SPEED_MAX = 400.0;
constexpr float STEPPER_MIN_RUN_SPEED = 30.0;
constexpr int POT_RAW_MIN = 2;
constexpr int POT_RAW_MAX = 3414;
constexpr int POT_HYSTERESIS = 8;
constexpr int POT_AVG_SAMPLES = 8;
constexpr uint32_t POT_UPDATE_MS = 50;

constexpr float MAX_SAFE_TEMP_C = 270.0;
constexpr uint32_t SERIAL_STATUS_LOG_INTERVAL_MS = 1500;
constexpr uint32_t SWITCH_POLL_MS = 20;
constexpr uint32_t BUTTON_DEBOUNCE_MS = 50;
constexpr int AVG_SAMPLES = 8;

constexpr bool SWITCH_ON_IS_LOW = false;

constexpr float TARGET_TEMP_DEFAULT = 255.0;
constexpr float TARGET_TEMP_MIN = 0.0;
constexpr float TARGET_TEMP_MAX = 270.0;
constexpr float TARGET_TEMP_STEP = 1.0;

// Bang-bang heater control around the user setpoint from app / temp buttons.
// OFF at >= target; ON again only after cooling to <= target - hysteresis.
constexpr float HEATER_HYSTERESIS_C = 3.0;
// true: GPIO HIGH turns heater ON (matches 05_Heater_Test_Safe).
// If HEAT shows 0% but temperature still rises, try false OR check MOSFET wiring.
constexpr bool HEATER_ACTIVE_HIGH = true;
constexpr uint32_t PID_UPDATE_MS = 250;  // heater control interval
constexpr int PID_MAX_OUTPUT = 255;         // used only for HEAT:% status (0 or 100)

// Legacy names kept so older helpers still compile.
constexpr float PID_CALIBRATION_OFFSET_C = 0.0;
constexpr float PID_APPROACH_BAND_C = 12.0;
constexpr float HEATER_RESUME_BAND_C = HEATER_HYSTERESIS_C;
constexpr int PID_KP = 90;
constexpr int PID_KI = 30;
constexpr int PID_KD = 80;
constexpr int PID_APPROACH_MAX_PWM = 180;
constexpr int PID_PWM_MAX_STEP = 30;
constexpr uint8_t HEATER_PWM_CHANNEL = 0;
constexpr uint32_t HEATER_PWM_FREQ = 7812;
constexpr uint8_t HEATER_PWM_BITS = 8;

AccelStepper stepper(AccelStepper::DRIVER, STEP_PIN, DIR_PIN);
hd44780_I2Cexp lcd;

bool machineRunning = false;

inline bool serialLoggingAllowed() {
#if PET_BENCH_NO_STEPPER_ON_UART
  return true;
#else
  return !machineRunning;
#endif
}

bool heaterState = false;
bool fanState = false;
bool heaterHoldOff = false;
uint8_t heaterPwmDuty = 0;

float pidError = 0.0f;
float pidPreviousError = 0.0f;
float pidIntegral = 0.0f;
float pidOutput = 0.0f;
unsigned long lastPidMs = 0;

unsigned long lastLcdMs = 0;
unsigned long lastSwitchPollMs = 0;
unsigned long lastTempPlusMs = 0;
unsigned long lastTempMinusMs = 0;
unsigned long lastPotMs = 0;

bool lastTempPlusState = HIGH;
bool lastTempMinusState = HIGH;

float targetTempC = TARGET_TEMP_DEFAULT;
float currentStepperSpeed = 0.0;
int stablePotRaw = 0;
float lastMeasuredTempC = NAN;

bool bleSpeedOverride = false;
bool lcdReady = false;
extern bool bleClientConnected;

bool appControlActive = false;
bool appWantsRunning = false;
bool lastRunSwitchOn = false;

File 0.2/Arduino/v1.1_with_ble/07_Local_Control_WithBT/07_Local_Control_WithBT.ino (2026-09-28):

// Bare-board CH343 testing: uncomment so STEP/DIR avoid UART0 (GPIO16/17).
// #define PET_BENCH_NO_STEPPER_ON_UART 1

#include <Wire.h>
#include <hd44780.h>
#include <hd44780ioClass/hd44780_I2Cexp.h>
#include <AccelStepper.h>
#include <math.h>
#include "pins_config.h"
#include "ble_config.h"

void waitForSerial(unsigned long timeoutMs = 3000) {
  unsigned long start = millis();
  while (!Serial && (millis() - start) < timeoutMs) {
    delay(10);
  }
}

void setup() {
  Serial.begin(115200);
  waitForSerial();
  delay(200);

  Serial.println();
  Serial.println("=== PET Recycle v1.1 (Local + BLE) ===");
  Serial.println("Boot: POWERON");
#if PET_BENCH_NO_STEPPER_ON_UART
  Serial.println("Bench mode: STEP/DIR on GPIO4/5, CH343 serial stays active");
#else
  Serial.println("Serial logging stops when motor runs (GPIO16/17 = CH343 + STEP/DIR)");
#endif

  pinMode(BTN_START_END, INPUT_PULLUP);
  pinMode(BTN_TEMP_PLUS, INPUT_PULLUP);
  pinMode(BTN_TEMP_MINUS, INPUT_PULLUP);
  pinMode(FAN_PIN, OUTPUT);
  pinMode(EN_PIN, OUTPUT);
  pinMode(STEP_PIN, OUTPUT);
  pinMode(DIR_PIN, OUTPUT);
  // STEP/DIR (GPIO16/17) share UART0 with CH343; AccelStepper claims them on first runSpeed().

  setupHeaterPwm();
  digitalWrite(FAN_PIN, LOW);
  setDriverEnable(false);
  Serial.println("GPIO init OK");

  analogReadResolution(12);
  Wire.begin(I2C_SDA_PIN, I2C_SCL_PIN);
  Wire.setTimeOut(1000);
  Serial.println("I2C init OK");

  int status = lcd.begin(16, 2);
  if (status) {
    lcdReady = false;
    Serial.print("LCD init FAILED, error=");
    Serial.println(status);
    Serial.println("Continue without LCD.");
  } else {
    lcdReady = true;
    Serial.println("LCD init OK");
    lcd.backlight();
    lcd.clear();
    lcd.setCursor(0, 0);
    lcd.print("LOCAL+BLE MODE");
    lcd.setCursor(0, 1);
    lcd.print("SET:");
    lcd.print(targetTempC, 0);
    lcd.print("C");
    delay(1200);
  }

  stepper.setMaxSpeed(STEPPER_SPEED_MAX);
  stepper.setSpeed(0);
  stablePotRaw = readAveragedPotRaw();
  Serial.println("Stepper init OK");

  lastRunSwitchOn = isRunSwitchOn();
  if (lastRunSwitchOn) {
    startAll();
    Serial.println("Run switch ON -> started");
  } else {
    stopAll();
    Serial.println("Run switch OFF -> stopped");
  }

  setupBle();
  printBleSerialHelp();
  Serial.println("Setup complete.");

  if (lcdReady) {
    lcd.clear();
  }
}

void loop() {
  handleRunSwitch();
  handleTempPlusButton();
  handleTempMinusButton();
  updateStepperSpeedFromPot();
  serviceStepper();

  int raw = readAveragedADC();
  double tempC = adcToTempC(raw);

  if (isnan(tempC)) {
    Serial.println("ERROR: Thermistor read failed");
    sensorFaultStop("Sensor Error");
  }

  if (tempC >= MAX_SAFE_TEMP_C) {
    Serial.print("ERROR: Over temp ");
    Serial.println(tempC, 1);
    overTempStop("Over Temp");
  }

  updatePidHeater(tempC);
  handleFanControl();
  serviceStepper();

  updateLCD(tempC);
  loopBle((float)tempC);
  serviceStepper();
  logMachineStatus((float)tempC);
}

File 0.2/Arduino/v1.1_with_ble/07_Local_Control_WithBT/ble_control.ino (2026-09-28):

#include <Preferences.h>
#include <BLEDevice.h>
#include <BLEServer.h>
#include <BLEUtils.h>
#include <BLE2902.h>
#include "ble_config.h"

Preferences blePrefs;
String bleDeviceName;

BLECharacteristic *bleControlChar = nullptr;
BLECharacteristic *bleStatusChar = nullptr;
BLECharacteristic *bleLogChar = nullptr;
BLEAdvertising *bleAdvertising = nullptr;

bool bleClientConnected = false;
int bleDeviceId = BLE_DEFAULT_DEVICE_ID;
unsigned long bleLastStatusNotifyMs = 0;

int clampBleDeviceId(int value) {
  if (value < BLE_DEVICE_ID_MIN) return BLE_DEVICE_ID_MIN;
  if (value > BLE_DEVICE_ID_MAX) return BLE_DEVICE_ID_MAX;
  return value;
}

float clampBleTemp(float value) {
  if (value < BLE_APP_TEMP_MIN) return BLE_APP_TEMP_MIN;
  if (value > BLE_APP_TEMP_MAX) return BLE_APP_TEMP_MAX;
  if (value < TARGET_TEMP_MIN) return TARGET_TEMP_MIN;
  if (value > TARGET_TEMP_MAX) return TARGET_TEMP_MAX;
  return value;
}

float clampBleSpeed(float value) {
  if (value < BLE_APP_SPEED_MIN) value = BLE_APP_SPEED_MIN;
  if (value > BLE_APP_SPEED_MAX) value = BLE_APP_SPEED_MAX;
  if (value < STEPPER_SPEED_MIN) value = STEPPER_SPEED_MIN;
  if (value > STEPPER_SPEED_MAX) value = STEPPER_SPEED_MAX;
  if (value > 0.0f && value < STEPPER_MIN_RUN_SPEED) {
    value = STEPPER_MIN_RUN_SPEED;
  }
  return value;
}

String buildBleDeviceName(int id) {
  return String(BLE_DEVICE_NAME_PREFIX) + String(id);
}

int loadBleDeviceId() {
  blePrefs.begin(BLE_PREFS_NAMESPACE, true);
  int storedId = blePrefs.getInt(BLE_PREFS_KEY_DEVICE_ID, BLE_DEFAULT_DEVICE_ID);
  blePrefs.end();
  return clampBleDeviceId(storedId);
}

void saveBleDeviceId(int id) {
  id = clampBleDeviceId(id);
  blePrefs.begin(BLE_PREFS_NAMESPACE, false);
  blePrefs.putInt(BLE_PREFS_KEY_DEVICE_ID, id);
  blePrefs.end();
  bleDeviceId = id;
  bleDeviceName = buildBleDeviceName(bleDeviceId);
}

String buildBleStatusString(float measuredTempC) {
  String msg = "TEMP:";
  if (isnan(measuredTempC)) {
    msg += "ERR";
  } else {
    msg += String((int)round(measuredTempC));
  }
  msg += ",TARGET:";
  msg += String((int)round(targetTempC));
  msg += ",HEAT:";
  msg += String((heaterPwmDuty * 100) / PID_MAX_OUTPUT);
  msg += ",SPEED:";
  msg += String((int)round(currentStepperSpeed));
  msg += ",STATUS:";
  msg += (machineRunning ? "ON" : "OFF");
  return msg;
}

void notifyBleStatus(float measuredTempC) {
  if (bleStatusChar == nullptr) return;

  String msg = buildBleStatusString(measuredTempC);
  bleStatusChar->setValue(msg.c_str());

  if (bleClientConnected) {
    bleStatusChar->notify();
  }
}

void notifyBleLog(const String& msg) {
  if (bleLogChar == nullptr) return;

  bleLogChar->setValue(msg.c_str());
  if (bleClientConnected) {
    bleLogChar->notify();
  }

  if (serialLoggingAllowed()) {
    Serial.print("BLE LOG -> ");
    Serial.println(msg);
  }
}

void applyBleSpeed(float speed) {
  currentStepperSpeed = clampBleSpeed(speed);
  bleSpeedOverride = true;

  if (machineRunning) {
    stepper.setSpeed(currentStepperSpeed);
  }
}

void processBleCommand(const String& cmdRaw, float measuredTempC) {
  String cmd = cmdRaw;
  cmd.trim();
  if (cmd.length() == 0) return;

  if (serialLoggingAllowed()) {
    Serial.print("BLE CMD <- ");
    Serial.println(cmd);
  }

  if (cmd == "START") {
    applyAppRunCommand(true);
    notifyBleLog("Machine started");
    notifyBleStatus(measuredTempC);
  } else if (cmd == "STOP") {
    applyAppRunCommand(false);
    notifyBleLog("Machine stopped");
    notifyBleStatus(measuredTempC);
  } else if (cmd.startsWith("SET_TEMP:")) {
    float value = clampBleTemp(cmd.substring(9).toFloat());
    // App setpoint replaces the boot default (255C) or any previous target.
    targetTempC = value;
    pidIntegral = 0.0f;
    pidPreviousError = 0.0f;
    if (!isnan(measuredTempC) && measuredTempC >= targetTempC) {
      setHeaterPwm(0);
    } else if (!isnan(measuredTempC) && measuredTempC <= (targetTempC - HEATER_HYSTERESIS_C)) {
      heaterHoldOff = false;
    }
    logSetTarget(targetTempC);
    notifyBleLog("Temp set to " + String(targetTempC, 0) + " C");
    notifyBleStatus(measuredTempC);
  } else if (cmd.startsWith("SET_SPEED:")) {
    float value = cmd.substring(10).toFloat();
    applyBleSpeed(value);
    notifyBleLog("Speed set to " + String((int)round(currentStepperSpeed)) + " mm/s");
    notifyBleStatus(measuredTempC);
  } else if (cmd == "GET_STATUS") {
    notifyBleStatus(measuredTempC);
  } else {
    notifyBleLog("Unknown command: " + cmd);
  }
}

void printBleSerialHelp() {
  Serial.println();
  Serial.println("BLE setup commands (115200 baud):");
  Serial.println("  GET_ID        Show saved device ID and BLE name");
  Serial.println("  SET_ID:2      Save device ID and restart board");
  Serial.println("  HELP          Show this help");
  Serial.println();
}

void processBleSerialCommand(const String& cmdRaw) {
  String cmd = cmdRaw;
  cmd.trim();
  if (cmd.length() == 0) return;

  Serial.print("SERIAL <- ");
  Serial.println(cmd);

  if (cmd == "HELP") {
    printBleSerialHelp();
  } else if (cmd == "GET_ID") {
    Serial.print("Device ID: ");
    Serial.println(bleDeviceId);
    Serial.print("BLE name: ");
    Serial.println(bleDeviceName);
  } else if (cmd.startsWith("SET_ID:")) {
    int newId = clampBleDeviceId(cmd.substring(7).toInt());
    if (newId == bleDeviceId) {
      Serial.println("Device ID unchanged.");
      return;
    }

    saveBleDeviceId(newId);
    Serial.print("Device ID saved as ");
    Serial.print(newId);
    Serial.println(". Restarting...");
    delay(300);
    ESP.restart();
  } else {
    Serial.println("Unknown serial command. Type HELP for options.");
  }
}

void readBleSerialCommands() {
  if (!serialLoggingAllowed()) return;

  static String serialBuffer;

  while (Serial.available() > 0) {
    char ch = Serial.read();
    if (ch == '\r') continue;

    if (ch == '\n') {
      processBleSerialCommand(serialBuffer);
      serialBuffer = "";
    } else {
      serialBuffer += ch;
    }
  }
}

class BleServerCallbacks : public BLEServerCallbacks {
  void onConnect(BLEServer *pServer) override {
    bleClientConnected = true;
    logBtState(true);
    notifyBleLog("BLE client connected");
  }

  void onDisconnect(BLEServer *pServer) override {
    bleClientConnected = false;
    logBtState(false);
    notifyBleLog("BLE client disconnected");
    releaseAppRunControl();

    delay(100);
    if (bleAdvertising != nullptr) {
      bleAdvertising->start();
      Serial.println("BLE advertising restarted");
    }
  }
};

class BleControlCallbacks : public BLECharacteristicCallbacks {
  void onWrite(BLECharacteristic *pCharacteristic) override {
    String rx = pCharacteristic->getValue();
    if (rx.length() > 0) {
      processBleCommand(rx, lastMeasuredTempC);
    }
  }
};
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

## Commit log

2026-02-25 Fix bugs in Firmware_1.ino and Android app
    [ControlActivity.java, Firmware_1.ino]
2026-02-25 Complete README with overview, BOM, firmware, Android app, and setup sections
2026-03-11 Add bottle filament extruder PCB (ESP32) image
    Add PNG image of the ESP32-based bottle filament extruder PCB to 0.2/docs. This adds a documentation asset for the hardware overview/reference.
2026-05-06 Add 3D models for spool holder sides A/B
    Add 3D source and STL files for spool holder sides A and B under 0.2/docs/3D model. Includes .blend and .blend1 source files and .stl exports for Side A (with and without logo) and Side B (without lo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
    [Spool_holder_side_A(without_logo).blend, Spool_holder_side_A(without_logo).stl, Spool_holder_side_A.stl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]
2026-05-22 Updated 0.2 PCB Board
    Updated PCB Board routing and generated Gerber folder and BOM components file
    [BOM_PET_PCB1_2026-05-22.xlsx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]
2026-05-23 Update PCB1 gerbers and BOM to 2026-05-23
    Regenerate PCB fabrication artifacts for PCB1 with 2026-05-23 timestamp. Files renamed/updated under 0.2/docs/Gerber_PCB1_2026-05-23 (Gerber layers, drill files, flying probe config) and a new Gerber_PCB1_2026-05-23.zip added. BOM spreadsheet (BOM_PET_PCB1_2026-05-22.xlsx) was updated, BottomSilkscreenLayer.GBO from the previous date was removed, and drill files include a new hole size (T13) plus coordinate adjustments. FlyingProbeTesting.json was reworked (added screw anchors and reordered entries). Informational How-to-order-PCB.txt carried over unchanged.
    [BOM_PET_PCB1_2026-05-22.xlsx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]
2026-05-25 chore: 把 .gitignore 統一移到專案根目錄
2026-05-25 chore: 刪除 .gitignore 文件
2026-05-25 chore: 新增 .gitignore 文件以排除不必要的檔案
2026-06-05 Update PCB1 Gerbers and BOM (2026-06-05)
    Replace the 2026-05-23 Gerber/BOM exports with updated 2026-06-05 outputs. Removed old Gerber_PCB1_2026-05-23 package and drill/testing files; added Gerber_PCB1_2026-06-05 ZIP and individual layer/drill/fabrication files, new FlyingProbeTesting.json, and an updated BOM_PET_PCB1_2026-06-05.xlsx. Also updated documentation images and added a new SCH PDF for the ESP32 board.
    [BOM_PET_PCB1_2026-05-22.xlsx, BOM_PET_PCB1_2026-06-05.xlsx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]
2026-06-27 0.2v esp32c6 firmware update with testing
2026-09-28 Update with Switch the v1.1 BLE firmware to bang-bang heat and quieter stepper control
    Update 07_Local_Control_WithBT so the heater, stepper, BLE status, and serial log match bench testing.
    Heater
    - Replace PID PWM with bang-bang control on GPIO6: ON at or below target minus 3°C, OFF at or above the target, and hold the last state in between.
    - Drive the gate digitally. HEATER_ACTIVE_HIGH means HIGH is ON. Any old PWM call is now full ON or full OFF.
    - Force the heater off when the machine stops, the reading is invalid, or the temperature passes the safe limit.
    - A BLE SET_TEMP replaces the boot default, clears the old control state, and applies the heater immediately.
    - Notify the app whe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
    [07_Local_Control_WithBT.ino, ble_config.h, ble_control.ino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]
